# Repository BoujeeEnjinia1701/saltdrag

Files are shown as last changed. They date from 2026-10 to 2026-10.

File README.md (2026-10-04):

# SaltDrag

     

**Area:** Food and water security · **TRL:** 3 of 9 (analytical proof of concept, constructable design) · **Value-engineering target:** USD 4,000; estimated cost USD 2,803 · **Difficulty:** 3 of 5

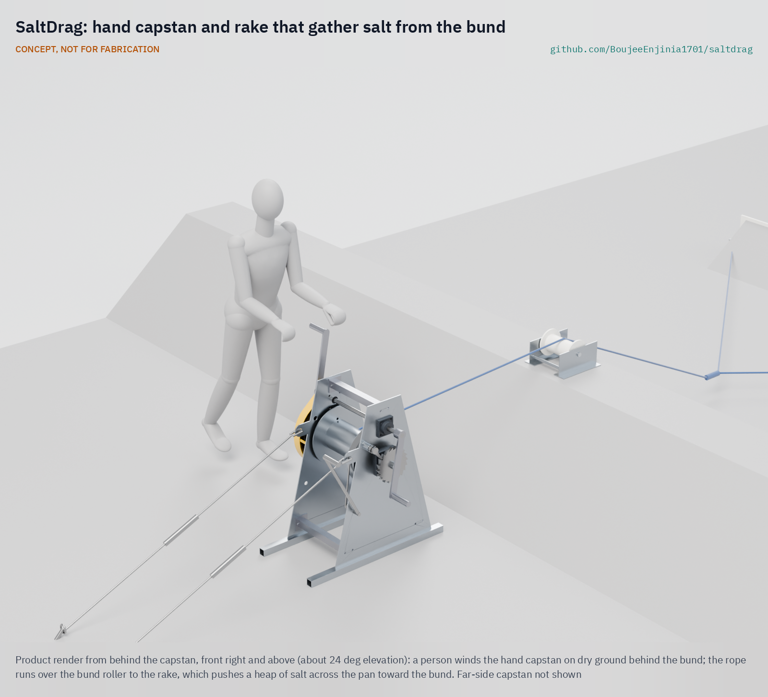
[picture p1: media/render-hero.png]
SaltDrag: hand capstan and rake that gather salt from the bund


[Exploded render](media/render-exploded.png) · [Detail render](media/render-detail.png) · [Interactive 3D model](media/viewer.html) · [Concept blueprint (PDF)](media/concept-blueprint.pdf)

Drags a rake across the salt pan with hand capstans on the bunds so workers stay out of the brine.

CONCEPT, NOT FOR FABRICATION: a TRL 3 design documented for building and testing, not a released or certified product.

## Concept rationale

Agariya families make salt by hand, and their own words describe the cost: from extreme winter to blazing sun they bear it all, and end up with grave injuries from constantly handling salt ([Mongabay India, 2021](https://india.mongabay.com/2021/10/when-salt-is-an-essential-commodity-and-salt-makers-are-not/)). SaltDrag moves the hardest part of the harvest out of the pan. A wide rake is laid across the pan and drawn over the crystal bed by ropes from two hand capstans set on the bunds. Workers wind the capstans from dry ground and the rake gathers the salt toward the bund, instead of people standing in the brine to scrape it.

It is hand powered on purpose. Agariyas received registration cards in 2023 on condition that they keep bunds to two feet and avoid machine use ([ICSF](https://icsf.net/newss/gujarat-in-kutch-booming-salt-business-puts-traditional-salt-agariyas-up-against-ginger-prawn-fishers/)), so a motorised harvester is not an option for them. A capstan and rake set that a local fabricator can build, within a prototype ceiling of $4,000 USD, and that a group of families can share, fits both the rules and the budget of a community that earns a small fraction of the retail price of its salt.

## Burning platform

About 60,000 Agariyas in the Little Rann of Kutch produce 30 per cent of India's inland salt, migrating to the pans for eight months a year; preparing each pan takes 40 to 45 days of manual work, and they earn about Rs 0.30 per kilogram for salt that retails at about Rs 20 ([Mongabay India, 2021](https://india.mongabay.com/2021/10/when-salt-is-an-essential-commodity-and-salt-makers-are-not/)). Salt pan workers there face severe health issues from working in harsh conditions for six to seven months at a stretch ([Wikipedia, citing The Diplomat](https://en.wikipedia.org/wiki/Little_Rann_of_Kutch)).

The collection season falls in the extreme heat of March and April ([Press Institute of India](https://pressinstitute.in/grassroots/traditional-salt-workers-contribute-to-wild-ass-conservation-and-regain-access-to-little-rann-of-kutch/)). Protective gear such as gumboots and caps has reached women workers through NGOs rather than employers ([Scroll.in](https://scroll.in/article/1007602/gujarats-plan-to-build-asias-biggest-freshwater-lake-is-a-threat-to-agariya-salt-workers)). The one big change in recent years, solar brine pumps, shows that the right hardware spreads fast: about 80 per cent of 7,000 Agariya families now have at least one solar pump ([Down To Earth](https://www.downtoearth.org.in/news/renewable-energy/great-change-in-little-rann-how-salt-workers-on-the-brink-in-gujarat-brought-about-a-solar-revolution-80652)). Harvesting has had no equivalent.

## Where it could be used

### By industry

| Industry | Use |
| --- | --- |
| Small-scale solar salt production | Gathering crystallised salt from inland and coastal pans without standing in brine |
| Cooperatives and producer groups | Shared harvest kit for a cluster of family pans |
| NGOs and livelihood programmes | Occupational health intervention alongside solar pumps and protective gear |
| Artisanal salt and specialty salt makers | Gentle, even gathering of large crystals from shallow pans |
| Evaporation pond operators | Low-cost manual scraping of small ponds and settling beds |

### By country or region

| Country or region | Why it matters there |
| --- | --- |
| India, Little Rann of Kutch | About 60,000 Agariyas produce 30 per cent of India's inland salt there by hand ([Mongabay India, 2021](https://india.mongabay.com/2021/10/when-salt-is-an-essential-commodity-and-salt-makers-are-not/)). |
| India, villages around the Rann | Agariyas migrate each season from 102 villages 7 to 45 km away, and 17.5 lakh people in the area depend on salt ([Scroll.in](https://scroll.in/article/1007602/gujarats-plan-to-build-asias-biggest-freshwater-lake-is-a-threat-to-agariya-salt-workers)). |
| India, Kutch coastal creeks | Salt works around Hadakiya Creek grew from 2,962 ha in 1995 to 15,950 ha in 2015, while Agariya registration requires two-foot bunds and no machine use ([ICSF](https://icsf.net/newss/gujarat-in-kutch-booming-salt-business-puts-traditional-salt-agariyas-up-against-ginger-prawn-fishers/)). |
| India, Gujarat | Gujarat produces 76 per cent of India's salt ([Press Institute of India](https://pressinstitute.in/grassroots/traditional-salt-workers-contribute-to-wild-ass-conservation-and-regain-access-to-little-rann-of-kutch/)). |

## What sparked the idea

An Agariya salt maker in the Little Rann of Kutch described the work this way: except pumping brine from the wells, everything is done manually, and "from extreme winter to blazing sun, we bear it all. And end up with grave injuries by constantly handling salt" ([Mongabay India, 2021](https://india.mongabay.com/2021/10/when-salt-is-an-essential-commodity-and-salt-makers-are-not/)). Solar pumps have changed the brine side of that sentence. SaltDrag is aimed at the other side: the handling.

## Problem

Small-scale salt makers such as the Agariyas of the Little Rann of Kutch gather crystallised salt by hand, working inside the pans for months in extreme heat and cold. There is no low-cost, non-motorised tool that lets them gather salt from the dry bund instead.

Full problem statement: [docs/01-problem.md](docs/01-problem.md)

## Concept

A 3 m rake is drawn across the salt pan by a rope from a hand capstan standing on dry ground behind the bund; the rope runs over a roller on the bund crest, and a second capstan on the far bund holds the rake straight and winds it back. Two people at 89 N each on 330 mm cranks pull a full heap of about 230 kg across a 30 m pan in under ten minutes (estimates, SDG-CAL-001). Every load-bearing part keeps at least a 2.1 margin at twice the rated 3 kN pull. The gathering rate against the traditional dantala is not yet known: it needs a baseline measured on a partner's pan.

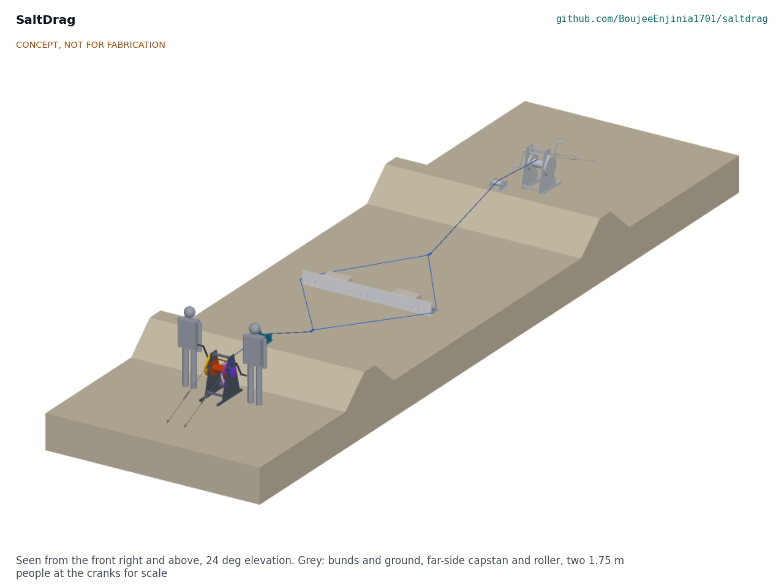
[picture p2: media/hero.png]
Working layout


Full design precis: [docs/02-concept.md](docs/02-concept.md) · Requirements: [docs/03-requirements.md](docs/03-requirements.md) · Calculations: [docs/04-calcs/01-sizing.md](docs/04-calcs/01-sizing.md) · Prototype build plan: [docs/05-build-plan.md](docs/05-build-plan.md) · Design decisions: [docs/06-design-decisions.md](docs/06-design-decisions.md) · General arrangement: [cad/drawings/SDG-DWG-001.pdf](cad/drawings/SDG-DWG-001.pdf) · 3D viewer: [media/viewer.html](media/viewer.html)

## Key components

- Hand capstans (two): geared drum winches, 6 to 1, with ratchet and pawl, band brake and gear guard
- Screw-in ground anchors and chains
- Bund roller saddles (two)
- Rake: 3.0 m FRP beam, 300 mm UHMW-PE blade, three skids, stainless end caps
- Pull ropes (12 mm polyester, 45 m each), bridles and swivels
- Rope dampers and ballast bags
- Maintenance kit

## Building the prototype

The build plan ([docs/05-build-plan.md](docs/05-build-plan.md)) takes a town fabrication shop through all 20 kinds of component in build order, with a making sketch for each made part, close-ups of the joints and a picture for every one of the 18 assembly steps. The capstans are cut, drilled and welded from steel plate and box section and then galvanised; the gears, bearings, anchors and ropes are bought; the rake is drilled FRP and plastic with stainless fittings. The plan is a plan, not yet built: it ends with first checks and the safety stops before any rope is loaded. The parts cost about USD 2,803 against a value-engineering target of USD 4,000.

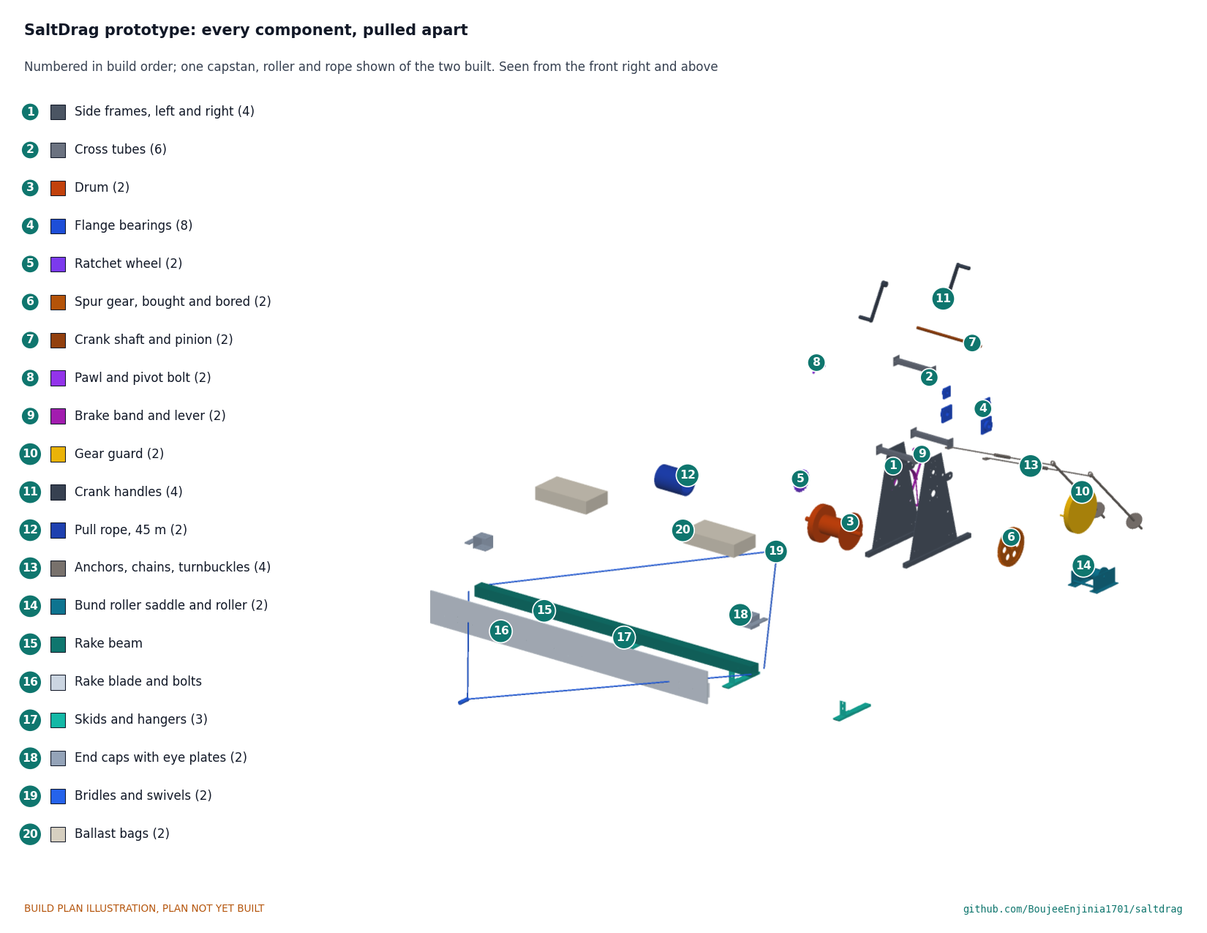
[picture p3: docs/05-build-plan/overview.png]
Every component, pulled apart and numbered in build order


## Safety

> Ropes under load can snap back. The design uses certified low-stretch polyester rope (working-load factor 7.7), a damper bag on every loaded rope and a 2 m exclusion zone along the rope line.
>
> Capstans have a pawl that is always engaged while winding, so a released crank cannot spin back; rope is paid out only on the band brake, with the crank handles removed. The gears run inside a guard.
>
> Ground anchors are proof-loaded on site before first use; the build plan lists safety stops before any rope load.
>
> Heat is a serious hazard in the harvest season; plan work for cooler hours and provide shade and water.
>
> Published as an open engineering reference, never as certified lifting or rope equipment.
>
> This design is published as an open engineering reference. It is not certified equipment.

## Repository layout

| Folder | Contents |
| --- | --- |
| `docs/` | Problem, concept, requirements, calculations, build plan and design decisions |
| `cad/src/` | build123d Python source, the source of truth for all geometry |
| `cad/step/`, `cad/stl/` | Exported models for FreeCAD, other CAD tools and printing |
| `cad/drawings/` | 2D sketches and dimensioned drawings |
| `bom/` | Bill of materials |
| `electronics/` | KiCad schematics and PCB layouts |
| `firmware/` | Microcontroller code |
| `media/` | Renders, perspectives and photos |
| `build-log/` | Dated prototyping notes |

## Documentation

Controlled documents follow the portfolio [documentation standard](.kit/STANDARDS.md). Each carries a document ID (SDG-PRC-001 for the precis), a version and a revision history. Branded PDFs are built with `python .kit/render.py` and attached to GitHub Releases when a document is tagged, for example `SDG-PRC-001/v1.0`.

## Credits

Designed by Amish Chadha at Design Molecule Labs. See [CONTRIBUTORS.md](CONTRIBUTORS.md) for roles. To cite this design, use [CITATION.cff](CITATION.cff) (GitHub shows it as "Cite this repository").

AI assistance (Claude) was used to accelerate prototype documentation and first-pass research. Design direction and all decisions are Amish Chadha's, recorded in this repository's decision records (`docs/decisions/`).

## Licenses

- **Hardware** (CAD, drawings, BOM, electronics): [CERN-OHL-S v2](LICENSE)
- **Software** (firmware, scripts, notebooks): [MIT](LICENSE-SOFTWARE)

A project of the [Design Molecule](https://designmolecule.com) lab.

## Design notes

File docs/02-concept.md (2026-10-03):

---
doc_id: SDG-PRC-001
title: SaltDrag design precis
project: SaltDrag
doc_type: Precis
version: "0.3"
status: Draft
date: '2026-10-03'
author: Amish Chadha
license: CERN-OHL-S-2.0
revisions:
- version: "0.1"
  date: '2026-09-30'
  author: Amish Chadha
  change: Initial scaffold
- version: "0.2"
  date: '2026-10-03'
  author: Amish Chadha
  change: TRL 2 precis; how it works, components, key design choices, first-order numbers, safety and concept media (SDG-DDR-001)
- version: "0.3"
  date: '2026-10-03'
  author: Amish Chadha
  change: TRL 3; numbers from SDG-CAL-001 and the constructable design (SDG-DDR-002); bund roller and ballast added, windrow board removed
---

# SaltDrag design precis

Drags a rake across the salt pan with hand capstans on the bunds so workers stay out of the brine.

Figure 1. SaltDrag working layout

*Figure 1. The working layout on a pan shortened to 7 m for the picture: the near capstan and bund roller in colour, the far-side set in grey, two 1.75 m people at the cranks for scale (concept media, SDG-DWG-010).*

## How it works

Two people winding a hand capstan on dry ground behind one bund draw a 3 m rake across the pan by a rope that runs over a roller on the bund crest. The rake's plastic blade rides 10 mm above the floor on three skids and pushes the loose salt crystals ahead of it into a heap of about 230 kg. At the near bund the steepening rope starts to lift the rake about 3.3 m from the bund toe, so the heap is left there as a windrow. A second capstan on the far bund holds a light back tension while the rake is pulled in, then winds it back empty. Both capstans then move 3 m along their bunds, and the return pull brings the rake onto the next strip. Nobody stands in the brine or walks on the pan at any stage.

Each capstan is a geared hand winch: two cranks drive a 14-tooth pinion, which turns an 84-tooth gear on the drum shaft (6 to 1). A pawl on a ratchet wheel stops the drum running back whenever the cranks are let go, and a band brake lets the far capstan pay out rope under control. Two chains from ears on the side frames, at rope height, hold the capstan to two screw-in ground anchors behind it.

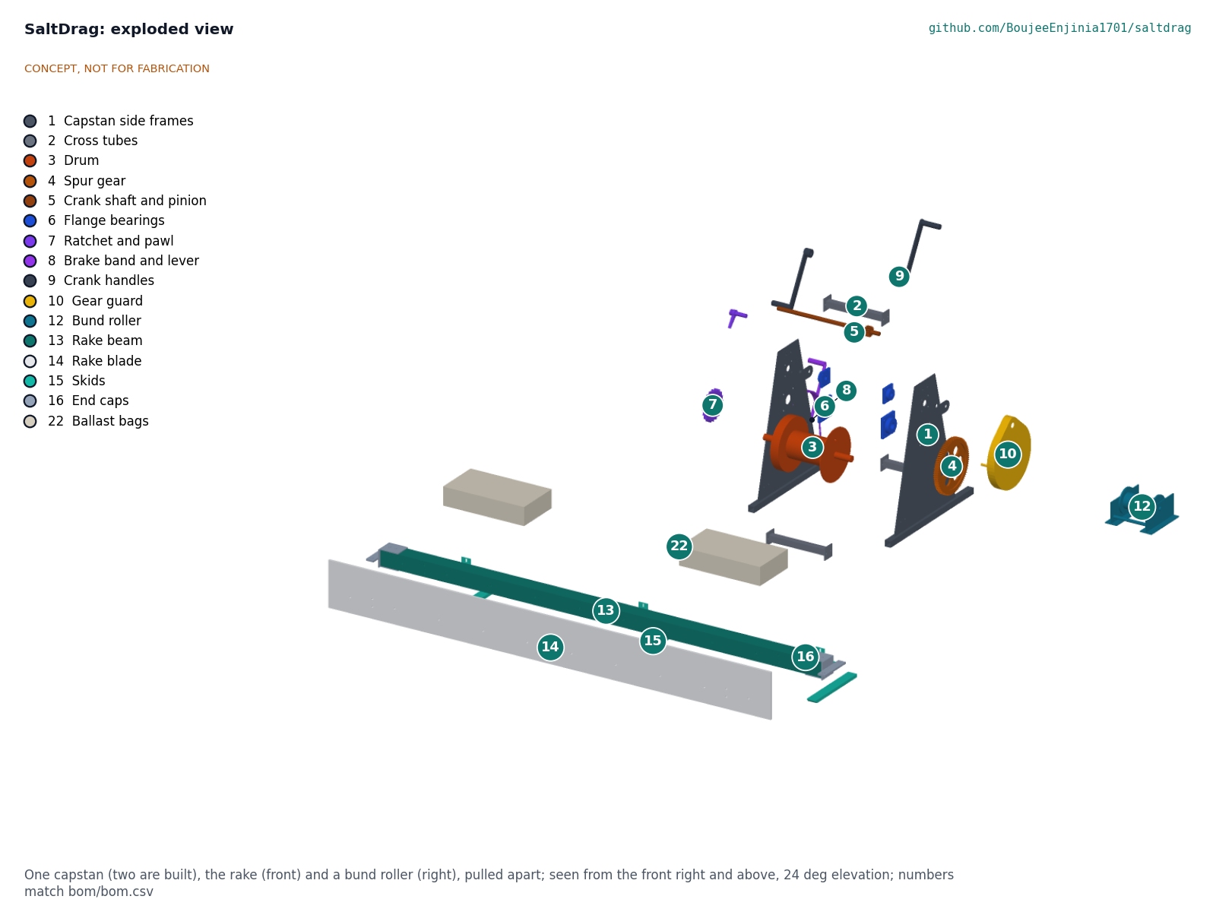
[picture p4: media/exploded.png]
Figure 2. Exploded view


*Figure 2. One capstan, the rake and a bund roller pulled apart; numbers match bom/bom.csv.*

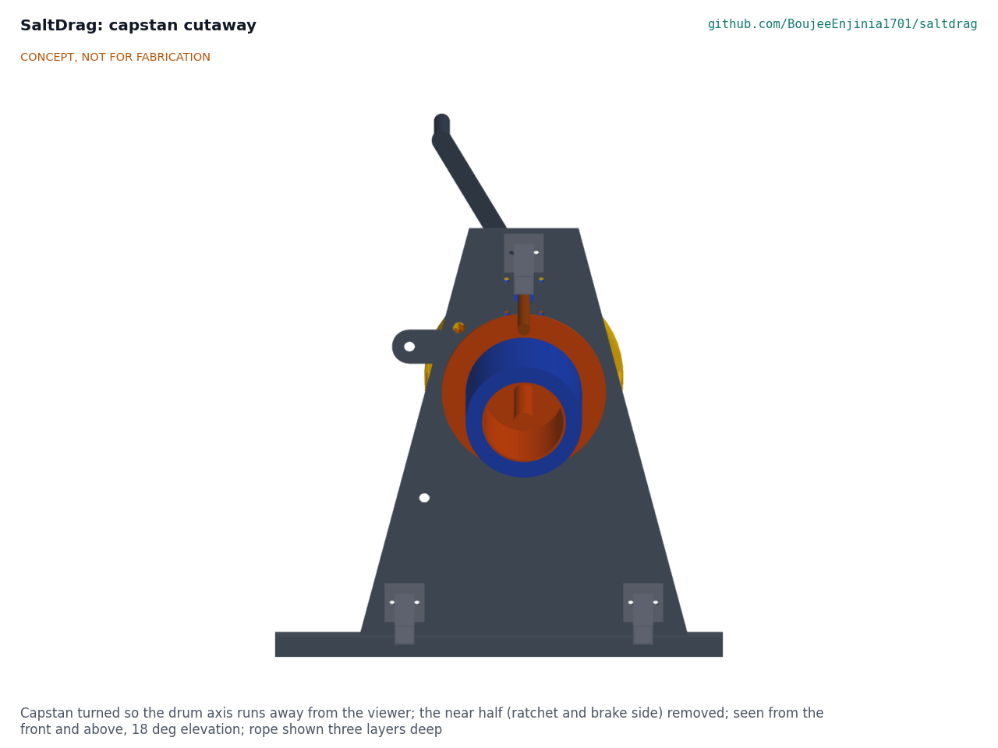
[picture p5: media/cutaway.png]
Figure 3. Capstan cutaway


*Figure 3. Capstan with its ratchet and brake side removed, showing the drum, flanges and three layers of rope.*

## Components

*Table 1. Main components (two capstans, two rollers and two ropes in a set).*

| BOM | Component | Role |
| --- | --- | --- |
| 1, 2 | Side frames and cross tubes | Two 6 mm galvanised cheeks on box-section runners, bolted together by three cross tubes; the runners let the capstan be slid along the bund |
| 3 | Drum | 168 mm barrel between 330 mm flanges on a 40 mm shaft; holds 58 m of 12 mm rope; the left flange carries the brake rim |
| 4, 5, 9 | Gear, crank shaft and pinion, crank handles | Module 4 spur gears, 6 to 1; two removable 330 mm cranks set 180 degrees apart |
| 6 | Flange bearings | Four-bolt bearings with stainless inserts in thermoplastic housings |
| 7, 8 | Ratchet and pawl; brake band and lever | The pawl holds the load; the band brake controls paying out |
| 10 | Gear guard | Yellow sheet-steel cup over the gear mesh |
| 11 | Ground anchors, chains and turnbuckles | Two screw-in anchors per capstan, chained to the cheek ears |
| 12 | Bund roller saddle | UHMW-PE roller on a small galvanised saddle astride the crest, so the rope never cuts the bund |
| 13 to 16 | Rake beam, blade, skids, end caps | 3.0 m FRP box beam with a 300 mm UHMW-PE blade; skids set the blade height; stainless end caps carry the bridle eyes |
| 17, 18 | Bridles and pull ropes | Two-leg polyester bridles to a swivel; 45 m of 12 mm polyester double braid per side |
| 20, 22 | Rope dampers and ballast bags | A weighted bag on each loaded rope; two salt-filled bags keep the blade down near the bund |
| 21 | Maintenance kit | Rinse water, grease and spares |

## Key design choices

All were decided on 2026-10-03 under Amish's pre-approval of this batch (SDG-DDR-001 and SDG-DDR-002; register SDG-DEC-001).

- **Drum winch, not a warping capstan.** The drum stores the rope, so nobody has to tail a loaded rope by hand.
- **Capstan behind the bund, roller on the crest.** A 0.4 m crest is too narrow for a capstan and two people cranking, and the roller keeps the rope off the bund.
- **Hand power, single spur stage.** No engine or motor, in keeping with the Agariya registration conditions.
- **Plastic and FRP in the pan, galvanised steel on dry ground.** Nothing that rusts sits in the brine.
- **One-piece 3 m rake with ballast.** The rake width keeps the design drag at the rated 3 kN; salt-filled bags keep the blade down as the rope steepens near the bund.

## First-order numbers

*Table 2. Key figures (estimates from SDG-CAL-001).*

| Quantity | Value | Basis |
| --- | --- | --- |
| Full heap in front of the blade | 0.19 m³, about 231 kg | 300 mm blade, 35 degree repose, 1,200 kg/m³ loose salt |
| Design drag on the rake | 2.75 kN | Heap sliding 1.59 kN, layer loosening 0.90 kN (assumed 300 N/m), skids 0.26 kN |
| Rope pull at the drum | 3.0 kN | Drag, roller loss and 200 N back tension |
| Crank force, two people | 89 N each | 6 to 1, 330 mm cranks, 94 % gear and bearing efficiency, rope on its third layer |
| Pull with two people at 120 N | 4.0 kN (3.7 kN on a full drum) | R3 asks for 3 kN |
| Rope speed and work rate | 3.1 m/min at 30 crank turns a minute; 84 W each | Light to moderate work, early hours in the hot season |
| One strip | 23 min: pull 9.5, return 5.7, move 8 | 30 m pan |
| Gathering rate | About 600 kg/h, 150 kg per worker-hour (crew of four) | Baseline for R5 still to be measured |
| Heaviest single part | 23.8 kg (ballast bag, filled on site); drum 21.3 kg | Model masses |
| Parts cost of the set | USD 2,803 | Value-engineering target USD 4,000 (USD 1,197 under) |

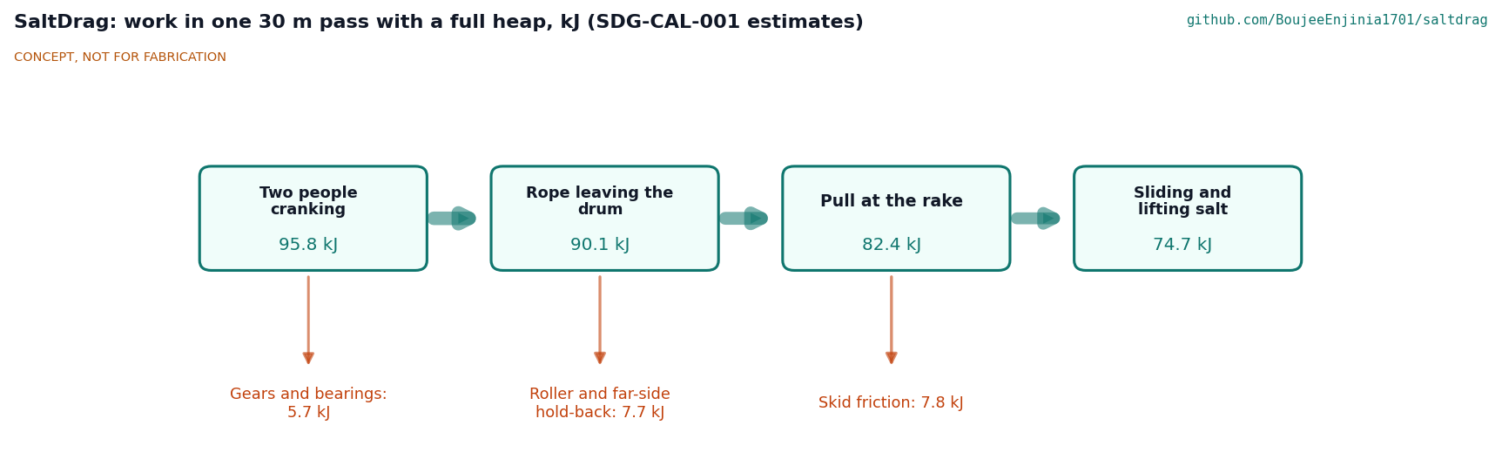
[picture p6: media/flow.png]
Figure 4. Work in one pass


*Figure 4. Where the cranking work goes in one 30 m pass with a full heap (estimates).*

## Patent design-arounds

From the preliminary patent, trademark and prior-art screen (not legal advice):

- No motorised or track-mounted auger harvester.
- Build on expired prior art such as the CA1243940A salt harvester; review CN102476810A (salt-pan rake) claims before release.

## Shared blocks

- Hand capstan common block, shared with SiltHaul: this capstan is the first candidate for the common block (SDG-DDR-001). SiltHaul is not changed by this work.
- CalRig proof-load for rope, capstan and anchor load tests.

## Safety

> **Safety:** A loaded rope stores energy and can whip back if it breaks, slips off the drum or loses its anchor. The rope is low-stretch polyester with a working-load factor of 7.7 at the rated pull, each loaded rope carries a weighted damper bag at mid-span, and nobody stands in line with a loaded rope or on the bund within 2 m of it.

> **Safety:** Cranks and gears can strike or trap hands. The pawl is always engaged while winding, so a released crank cannot spin back; the gears run inside a yellow guard; the crank handles are taken off before any rope is paid out under load, and paying out is done only on the brake.

> **Safety:** A ground anchor that pulls out lets the capstan lurch toward the pan. Each anchor is proof-loaded on site to 1.5 times its share of the rated pull before first use, and the chains are fixed at rope height so the capstan cannot tip.

> **Safety:** Heat is a serious hazard in the harvest season; plan work for cooler hours and provide shade and water. Parts of up to 24 kg are lifted and carried; lift in pairs.

This design is published as an open engineering reference, never as certified lifting or rope equipment. It is not certified equipment.

## Open questions

No design decisions are open (register SDG-DEC-001). Facts that only a site survey or real parts can settle, such as the drag per metre on a real crystal bed, the bund crest width and the soil behind the bunds, are listed in the register to be confirmed.

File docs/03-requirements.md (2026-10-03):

---
doc_id: SDG-REQ-001
title: SaltDrag requirements
project: SaltDrag
doc_type: Requirements
version: "0.3"
status: Draft
date: '2026-10-03'
author: Amish Chadha
license: CERN-OHL-S-2.0
revisions:
- version: "0.1"
  date: '2026-09-30'
  author: Amish Chadha
  change: Initial scaffold
- version: "0.2"
  date: '2026-10-03'
  author: Amish Chadha
  change: TRL 2; every target made measurable; R10 to R12 added for rope, holding and rope capacity (SDG-DDR-001)
- version: "0.3"
  date: '2026-10-03'
  author: Amish Chadha
  change: TRL 3 status from SDG-CAL-001 against the constructable design (SDG-DDR-002); R5 not verified
---

# SaltDrag requirements

Eleven of the twelve requirements are met on paper by the constructable design; R5, the gathering rate against the dantala, cannot be shown until the dantala baseline is measured on a partner's pan. Status is from the sizing note SDG-CAL-001 (estimates). Physical verification is TRL 4 and TRL 5 work.

*Table 1. Requirements and their status at TRL 3.*

| ID | Requirement | Target | Verification (TRL 4 or later) | TRL 3 status |
| --- | --- | --- | --- | --- |
| R1 | Work from the bund | A full harvest pass, including set-up and moving to the next strip, with no worker entering the pan | Observed field trial on a partner pan | Met by design: crews stand on dry ground behind the bunds; the return pull re-aligns the rake |
| R2 | Manageable crank effort | 120 N or less at each of two handles for the design rake load | Spring scale on the handle during trials | Met: 89 N estimated [B3] |
| R3 | Pull capacity | At least 3 kN rope pull from two people at 120 N; every load-bearing part at least 2 to 1 on yield or rated strength at 6 kN | Proof-load test with CalRig | Met: 4.0 kN at the end of a 30 m pass, 3.7 kN on a full drum [B4], [B5]; lowest margin 2.1 [C2b] |
| R4 | Protect the pan floor | Blade edge 5 to 25 mm above the floor; no steel in the pan; skid pressure 15 kPa or less; no visible cutting or cracking after 20 passes | Inspection of a test pan after trial passes | Met by design: 10 mm edge, 10.7 kPa [D1], [D2]; floor check at TRL 5 |
| R5 | Gathering rate | At least as many kilograms per worker-hour as the dantala method on the same pan | Side-by-side timed harvest trial | **Not verified**: no baseline yet; estimate 150 kg per worker-hour [D9] |
| R6 | Portable | Heaviest single part 25 kg or less; every part of the set carried by up to four people | Weigh parts; timed move between pans | Met: heaviest 23.8 kg (a ballast bag filled on site), drum 21.3 kg [E1] |
| R7 | Corrosion resistance | No loss of function after one season in brine and salt with a daily freshwater rinse | Season-long field trial with inspection log | Met by design: galvanised steel above the bund; FRP, UHMW-PE and 316 stainless in the pan |
| R8 | Quick set-up | Capstans anchored and rake rigged in 20 minutes or less (two crews at once) | Timed trials | Met: 19 min estimated [D10], small margin |
| R9 | Value engineering | Parts cost of the full set against the value-engineering target of USD 4,000 | Costed bill of materials | USD 2,803, USD 1,197 under the target [E2], [E3] |
| R10 | Rope safety | Rope minimum breaking strength, after splices, at least 5 times the rated 3 kN pull | Rope certificate; proof load | Met: 7.7 [C8] |
| R11 | Holding | Pawl holds 6 kN; brake holds 3 kN with a hand force of 150 N or less; each ground anchor holds at least 1.5 times its share of the rated pull (proof-loaded on site before use) | Proof-load test with CalRig; anchor pull test on site | Met on paper: pawl boss margin 4.7 [C5b], brake 92 N [C7], anchor 2.4 times its 6 kN chain force [C10b] (soil to confirm) |
| R12 | Pan coverage | Each drum stores at least 45 m of rope, for pans up to 30 m between bund crests | Wind on and measure | Met: 58 m in four layers, 38 mm flange freeboard [B8], [B9] |

## Assumptions

- The drag of a rake on a crystallised bed is about 0.9 kN per metre of blade with a full heap (SDG-CAL-001, Section A); this is the main uncertainty and is measured with the partner before the first build is loaded.
- Hand capstans are not treated as machines under Agariya registration conditions; written clarification is sought through the partner before any trial.
- Several families can share one set across a harvest season.
- Salt gathered into the windrow, about 3.3 m from the bund toe, is loaded with existing methods (out of scope).
- The pans have dry, firm ground behind the bunds on the two sides where the capstans stand.

> **Safety:** R3, R10 and R11 are safety requirements. A load-bearing part that misses its margin, a rope without a certificate, or an anchor that fails its proof load on site stops the work until it is replaced (SDG-BLD-001, Safety stops).

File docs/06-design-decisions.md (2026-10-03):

---
doc_id: SDG-DEC-001
title: SaltDrag design decisions register
project: SaltDrag
doc_type: Design decisions register
version: "0.1"
status: Draft
date: '2026-10-03'
author: Amish Chadha
license: CERN-OHL-S-2.0
revisions:
- version: "0.1"
  date: '2026-10-03'
  author: Amish Chadha
  change: Register opened at TRL 3; every decision made under Amish's 2026-10-03 pre-approval
---

# SaltDrag design decisions register

Every design decision still to be made, and every decision made, in one place. Each decision is argued in full in its decision record under `docs/decisions/`; this register is the index Amish works from. The build plan (`docs/05-build-plan.md`) describes the design as it stands and does not list open decisions.

## Open decisions

None. All decisions were made under Amish's 2026-10-03 pre-approval.

## To confirm when parts are bought

| # | What to confirm | Why it matters | Source |
| --- | --- | --- | --- |
| 1 | The rope certificate shows a minimum breaking strength of at least 25 kN for the 12 mm polyester double braid, with eye splices | The 7.7 working-load factor (R10) rests on it | SDG-CAL-001 [C8] |
| 2 | The bought gear and pinion are module 4, 20 degree pressure angle, C45 or better, and the gear blank is webbed (about 10 kg) | Tooth strength, mesh at 196 mm centres and the part mass | SDG-CAL-001 [C3]; SDG-DDR-002 |
| 3 | The flange bearings fit 40 mm and 25 mm shafts on bolt squares of 102 mm and 70 mm, with stainless inserts | The cheek holes are drilled to these squares | SDG-DWG-101 |
| 4 | The chain, turnbuckles and shackles carry working load limits of at least 7.8 kN, 6 kN and 10 kN | The 2.4 margin on the chain line | SDG-CAL-001 [C9b] |
| 5 | The FRP tube's maker gives a flexural strength of 200 MPa or more | The beam margin of 7.1 | SDG-CAL-001 [C13b] |
| 6 | Each helical anchor holds at least 2.25 kN (1.5 times its share of the rated pull) in the proof pull on site, at the trial pan | The soil strength is assumed at 50 kPa; the anchors are a safety stop | SDG-CAL-001 [C10]; SDG-DDR-001, D11 |
| 7 | The drag of the rake on the partner's crystal bed, measured with a spring scale or CalRig on a short trial rake | The design drag and rope pull rest on an assumed 300 N per metre; if higher, raise the skids or shorten the rake | SDG-CAL-001, Section A |
| 8 | The bund crest is at least 0.35 m wide and the ground behind the bund is firm and dry on both capstan sides of the trial pan | The roller saddle footprint and capstan position assume it | SDG-PRB-001; SDG-DDR-001, D2 |

## Value engineering

Value-engineering target: USD 4,000 (a hypothetical control target, not a limit). Estimated cost of the constructable design: USD 2,803 (USD 1,197 under the target). Main cost drivers and savings worth trying:

- The largest lines are fabrication labour and galvanising (USD 450), the four side frames (USD 220), the two drums (USD 220), the two bought gears (USD 190), the rake blade (USD 190) and the two pull ropes (USD 190).
- The four flange bearings with stainless inserts (USD 264 for eight) cost about twice plain cast-iron bearings; they stay because the capstans stand in salt dust and are rinsed daily.
- Savings worth trying: a single gear pair cut in a local workshop in place of bought gears; a laser-cut cheek nested with the ratchet wheel and pawl to cut plate waste; sharing one set between several families' pans, which spreads the cost per family.

## Decisions made

| Date | Decision | Decided by | Record |
| --- | --- | --- | --- |
| 2026-10-03 | Geared drum winch (still called a hand capstan) rather than a warping capstan | Amish, pre-approval: "I pre-approve the batch runs along with any recommendations you come up with." | SDG-DDR-001, D1 |
| 2026-10-03 | Capstan on dry ground 1.5 m behind the bund crest, with a bund roller saddle on the crest | Amish, same pre-approval | SDG-DDR-001, D2 |
| 2026-10-03 | Single spur stage 6 to 1, module 4; two 330 mm cranks 180 degrees apart | Amish, same pre-approval | SDG-DDR-001, D3 |
| 2026-10-03 | 12 mm polyester double braid rope, 45 m per side | Amish, same pre-approval | SDG-DDR-001, D4 |
| 2026-10-03 | One-piece 3.0 m FRP rake with a 300 mm UHMW-PE blade; three adjustable skids, blade 10 mm above the floor | Amish, same pre-approval | SDG-DDR-001, D5 and D6 |
| 2026-10-03 | Two helical ground anchors per capstan, chained at rope height | Amish, same pre-approval | SDG-DDR-001, D7 |
| 2026-10-03 | Galvanised steel on dry ground; FRP, UHMW-PE and 316 stainless in the pan; stainless-insert bearings; daily rinse | Amish, same pre-approval | SDG-DDR-001, D8 |
| 2026-10-03 | Safety: pawl always engaged while winding; pay out only on the brake with the cranks removed; rope dampers and a 2 m exclusion zone; anchors proof-loaded on site to 1.5 times their share | Amish, same pre-approval (conservative options) | SDG-DDR-001, D9 to D11 |
| 2026-10-03 | Design pan 30 m between crests; crew of four | Amish, same pre-approval | SDG-DDR-001, D12 and D13 |
| 2026-10-03 | First co-design partner to approach: SEWA; first trial region: Little Rann of Kutch (candidates, not agreed) | Amish, same pre-approval | SDG-DDR-001, D14 and D15 |
| 2026-10-03 | Seek written clarification from the forest department, through the partner, that a hand capstan is not a machine | Amish, same pre-approval | SDG-DDR-001, D16 |
| 2026-10-03 | SaltDrag capstan offered as the first candidate for the hand capstan block shared with SiltHaul | Amish, same pre-approval | SDG-DDR-001, D17 |
| 2026-10-03 | Design for construction: bolted side frames and cross tubes, welded drum with brake rim, flange bearings, bought gears, pawl on a welded boss, differential band brake, removable cranks, gear guard, anchor ears and chains, one-piece rake with crush-sleeved bolts, slotted skid hangers, end caps with eye plates | Amish, same pre-approval | SDG-DDR-002, changes 1 to 14 |
| 2026-10-03 | Ballast bags on the rake; windrow board removed (the windrow forms about 3.3 m from the bund toe); rope dampers added | Amish, same pre-approval | SDG-DDR-002, changes 15 to 17 |
| 2026-10-03 | Estimated cost reported against the unchanged value-engineering target of USD 4,000 | Amish: "I also accept any cost overruns or variations from the assumed scope cost." | This register |

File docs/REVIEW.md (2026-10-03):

# Review note: SaltDrag

## Session 2026-09-30: scaffolded

### What was done

- Repository created from kit 1.6.0 at TRL 1, target TRL 2.
- `docs/01-problem.md` (SDG-PRB-001 v0.1): problem with cited evidence, users, environment, constraints, prior work, open questions.
- `docs/02-concept.md` (SDG-PRC-001 v0.1): how it works, components, patent design-arounds, shared blocks, safety.
- `docs/03-requirements.md` (SDG-REQ-001 v0.1): 9 proposed requirements.
- `README.md` with concept rationale, burning platform, where it could be used, and what sparked the idea.

### Next

- Run `/populate` to bring the repo to a strong TRL 2 with concept media.

## Session 2026-10-03: TRL 2 (/populate, kit 1.7.0)

Kit 1.7.0 installed (`.kit/`, `.claude/commands/`, root `CLAUDE.md` from `.kit/CLAUDE.md`). Run under Amish's pre-approval of 2026-10-03: "start with the first 14 repos from the list of 29 projects. I pre-approve the batch runs along with any recommendations you come up with. I also accept any cost overruns or variations from the assumed scope cost." Every recommendation is therefore recorded as decided, not proposed.

### What was done

- `docs/01-problem.md` (SDG-PRB-001 v0.2): site assumptions stated (30 m design pan, 0.4 m crest, dry ground behind the bunds), co-design checklist, safety section, open questions answered where the work settles them.
- `docs/03-requirements.md` (SDG-REQ-001 v0.2): every target measurable; R10 (rope safety), R11 (holding) and R12 (rope capacity) added.
- `docs/02-concept.md` (SDG-PRC-001 v0.2): how it works, components, key design choices, first-order numbers, safety, concept media.
- `docs/decisions/0001-trl2-review-decisions.md` (SDG-DDR-001): TRL 2 review decisions D1 to D17.
- Concept media from `cad/src/concept_media.py`: `media/hero.png`, `media/concept-blueprint.png`, `.pdf` and `.svg` (SDG-DWG-010), `media/model.glb` (about 4 MB) and `media/viewer.html`, `media/exploded.png`, `media/cutaway.png`, `media/flow.png` (work per pass, estimates).
- `bom/bom.csv`: every line priced.

### Results

- A geared drum winch (6 to 1, two 330 mm cranks) on dry ground behind the bund, a roller on the crest, and a 3 m FRP and UHMW-PE rake set to 10 mm above the floor.
- The rake width follows from the drag estimate: a full 230 kg heap gives a design rope pull of 3.0 kN, the rated pull.

### Requirements not met

- R5 (gathering rate at least the dantala's) cannot be shown: there is no baseline yet.

### Decisions made under the pre-approval

SDG-DDR-001, D1 to D17: drum winch, capstan behind the bund with a crest roller, single spur stage, polyester rope, one-piece FRP rake, adjustable skids, helical anchors chained at rope height, materials for brine, conservative safety rules (pawl always on, pay out on the brake with cranks removed, dampers and a 2 m exclusion zone, anchors proof-loaded on site), 30 m design pan, crew of four, SEWA as the first co-design partner to approach and the Little Rann as the first trial region (candidates, not agreed), written clarification on the machine-use condition, and the capstan as the first candidate for the block shared with SiltHaul.

### Safety concerns

Rope snap-back, cranks and gears, anchor pull-out and heat. See SDG-PRC-001, Safety.

## Session 2026-10-03: TRL 3 (/advance-trl3 and /build-plan)

### What was done

- `docs/04-calcs/01-sizing.md` (SDG-CAL-001 v0.2) with `docs/04-calcs/sizing.py` and `docs/04-calcs/results.csv`: drag, capstan, strength at 6 kN, floor, lift-off near the bund, rate, set-up, mass and cost, with a results table against every requirement.
- `cad/src/model.py`: parametric build123d model of the capstan, rake, roller and layout, with 63 constructability checks (`--check`: 63 of 63 pass). STEP and STL in `cad/step/` and `cad/stl/` (capstan, rake, roller; assembly STEP of the layout).
- `cad/src/sheets.py`: general arrangement SDG-DWG-001 Rev P2 (Rev P1 superseded the same day by the design for construction).
- `cad/src/build_plan_media.py`: overview, 13 making sketches (SDG-DWG-101 to 113), 11 joint close-ups and 18 step pictures.
- `docs/05-build-plan.md` (SDG-BLD-001 v0.1), `docs/06-design-decisions.md` (SDG-DEC-001 v0.1), `docs/decisions/0002-design-for-construction.md` (SDG-DDR-002).
- `cad/src/product_model.py` (`product_parts()`, `TITLE`, `RENDER_VIEWS` hero, exploded and detail) and render scenes exported to `/home/claude/renders/saltdrag` for the photoreal renders on Amish's Mac.
- `docs/02-concept.md` v0.3, `docs/03-requirements.md` v0.3, `README.md` (TRL 3, hero render, links, Building the prototype), `project.yaml` (trl 3, trl_target 3, design_state constructable, trl_evidence). `budget_usd` unchanged.

### Results (estimates, SDG-CAL-001)

- Crank force 89 N per handle at the design drag (R2: 120 N); two people at 120 N pull 4.0 kN (3.7 kN on a full drum) against 3 kN asked (R3).
- Lowest strength margin at 6 kN: crank shaft 2.1 on yield; rope working-load factor 7.7; anchors 2.4 on their chain force (soil assumed).
- A 30 m pass takes 9.5 min; one strip 23 min; about 600 kg/h, 150 kg per worker-hour for a crew of four.
- Capstan 102 kg assembled; heaviest single part 23.8 kg (a ballast bag filled on site), drum 21.3 kg.
- Value-engineering target: USD 4,000. Estimated cost of the constructable design: USD 2,803 (USD 1,197 under the target).

### Requirements not met

- R5 is not verified: no dantala baseline. The estimate of 150 kg per worker-hour may be below the dantala rate; if it is, the cycle (8 min moving per 3 m strip) is the first place to look.
- R8 is met with a small margin (19 min against 20).

### Decisions made under the pre-approval

- SDG-DDR-002, changes 1 to 17 (below), and the value-engineering wording of the cost.
- Open decisions in SDG-DEC-001: none. Eight facts to confirm when parts are bought or at the trial pan are listed there (rope certificate, gears, bearings, rigging ratings, FRP strength, anchor holding, measured drag, bund and ground survey).

### Design changes made for construction (SDG-DDR-002)

1. Capstan frame of two bolted side frames (cheek on runner) and three cross tubes.
2. Capstan on dry ground behind the bund; bund roller saddle on the crest (new BOM 12).
3. Welded drum with brake rim; rope over the top.
4. Flange bearings on the cheeks (new line 6b for the 25 mm size).
5. Bought webbed gear and pinion, keyed.
6. Pawl on a 40 mm welded boss (a plain pin would bend at 6 kN).
7. Differential band brake through the left cheek.
8. Removable crank handles with cross pins.
9. Gear guard.
10. Anchor ears at rope height, shackles, chains and turnbuckles (new line 11b).
11. One-piece 3 m FRP beam.
12. Blade bolts with crush sleeves.
13. Skids on slotted stainless hangers.
14. End caps with eye plates for the bridles.
15. Ballast bags (new line 22): without them the rope lifts the blade 5.9 m from the bund toe; with them, 3.3 m.
16. Windrow board removed: the windrow forms about 3.3 m from the toe.
17. Rope dampers (new line 20); fabrication labour and galvanising priced as line 23.

### Build plan findings

- The near-bund lift-off is the main finding the concept missed; it sets the windrow 3.3 m into the pan, so loading out still uses existing methods.
- Moving both capstans 3 m per strip (8 min) is a third of the cycle; a sliding anchor line along the bund is worth studying at TRL 4.
- The drum and gears must be bought or machined; everything else is town-workshop work.

### Appearance model and render scenes

- `cad/src/product_model.py` takes every part from `model.py`'s layout. Departures from `model.py`: the ground anchors are cut off at ground level (they are buried), the crank is drawn at 100 degrees (`crank_angle`) so the cranking figure's hands meet the upper handle, the rake is drawn 2.5 m from the bund toe with a heap of salt in front of it (context), and the far-side set is not shown. Decided under the pre-approval.
- Scenes exported with `.kit/export_views.py` to `/home/claude/renders/saltdrag` (hero, exploded, detail). `media/render-hero.png` is made on Amish's Mac; until then `render.py --check` warns that it is missing.

### Safety concerns

- Rope snap-back: certified rope, dampers, exclusion zone; safety stops S2, S3 and S5.
- Cranks and gears: guard, pawl always on, cranks off before paying out (S4).
- Anchor pull-out: on-site proof pull of every anchor (S6, S7); soil strength is an assumption.
- Heat in the harvest season: work in cooler hours with shade and water; each cranker works at about 84 W.
- The drag per metre is assumed; it is measured before the first loaded pass (SDG-DEC-001, item 7).

### Recommended next step

The design is ready for TRL 4 on paper. Recommendation: with the co-design partner, measure the drag of a short trial rake and time the dantala on the same pan, then build one capstan and proof-load it with CalRig before building the full set.

### Cross-repo note (not edited)

SiltHaul names the hand capstan as a shared block; SaltDrag's capstan (SDG-DWG-101 to 108) is offered as the first candidate.

## 2026-10-03: photoreal renders

Rendered with Blender Cycles on Amish's Mac from `cad/src/product_model.py`; captioned with `.kit/photo_caption.py`; `media/card.png` and `media/social-preview.png` made with `.kit/cards.py`. Views: hero, exploded, detail. image_qc passes and `render.py --check` has no FAIL.

2026-10-03: hero render reframed so the product fills the frame (saltdrag).

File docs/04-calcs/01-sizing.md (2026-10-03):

---
doc_id: SDG-CAL-001
title: SaltDrag sizing calculations
project: SaltDrag
doc_type: Calculation
version: "0.2"
status: Draft
date: '2026-10-03'
author: Amish Chadha
license: CERN-OHL-S-2.0
revisions:
- version: "0.1"
  date: '2026-10-03'
  author: Amish Chadha
  change: First sizing note at TRL 3 (drag, capstan, strength, floor, rate, mass and cost)
- version: "0.2"
  date: '2026-10-03'
  author: Amish Chadha
  change: Rerun on the constructable design (SDG-DDR-002); pawl boss, ballast and lift-off near the bund added
---

# SaltDrag sizing calculations

Two people at 89 N each on 330 mm cranks can pull a 3 m rake with a full 230 kg heap across a 30 m pan in under ten minutes, and every load-bearing part keeps at least a 2.1 margin on yield at twice the rated 3 kN pull. Eleven of twelve requirements are met on paper. R5, the gathering rate against the dantala, cannot be shown until the dantala baseline is measured; the estimate is 150 kg per worker-hour. The largest uncertainty is the drag of a rake on a real crystal bed, which is assumed here and must be measured before the first build is loaded.

## Scope and method

First-order hand calculations, scripted in `docs/04-calcs/sizing.py`, which reads its geometry and masses from the parametric model (`cad/src/model.py`) and the bill of materials, prints every result with a label in square brackets, and writes `docs/04-calcs/results.csv`. Strength checks use twice the rated rope pull (6 kN), as R3 asks. All results are estimates for TRL 3; none is a test result.

## Assumptions

*Table 1. Assumptions (every one is in the script's ASSUME list).*

| Assumption | Value | Basis |
| --- | --- | --- |
| Loose salt bulk density | 1,200 kg/m³ | Typical 1,100 to 1,300 for crystallised salt |
| Heap repose angle; heap sliding friction | 35 degrees; 0.70 | Granular salt; friction taken as tan 35 degrees |
| Allowance to loosen and lift the harvest layer | 300 N per metre of blade | Estimate; to be measured with the partner (PRB open questions) |
| Skids on wet salt | friction 0.30 | UHMW-PE on a wet crystalline surface |
| Back tension from the far capstan | 200 N | Enough to keep the rake square |
| Efficiencies | roller 0.98, one spur stage 0.96, bearings 0.98 | Greased gears with some dust |
| People | two crankers at up to 120 N; 30 turns a minute under load, 50 on the return | R2; sustained cranking |
| Moving to the next strip | 8 min | Unchain, slide both capstans 3 m, move the rollers, re-anchor |
| Crew | four | Two cranking near, one at the far capstan, one with rollers and ropes |
| Rope | 12 mm polyester double braid, 27 kN minimum breaking strength, splices 85 % | Catalogue class; certificate to confirm |
| Steels | C45 yield 340 MPa; S275 yield 275 MPa | Normalised bar; structural plate |
| FRP beam | flexural strength 200 MPa, modulus 23 GPa | Lower-bound pultruded values |
| Soil behind the bund | firm clay, undrained shear strength 50 kPa; helix bearing factor 9 | To confirm by a pull test on site |
| Brake lining | friction 0.30 | Woven lining on steel, dusty |
| Design pan | 30 m between bund crests | Assumption, to be surveyed |

## A. Drag on the rake (R2, R3)

The rake is sized so that its design drag with a full heap matches the rated 3 kN pull.

- Full heap: a 300 mm blade holds a heap of triangular section, 0.0643 m² over 3.0 m, or 0.19 m³ [A1], about 231 kg [A2].
- Sliding the full heap over the bed: 0.70 x 231 kg x 9.81 = 1,589 N [A3].
- Loosening and lifting the harvest layer: 300 N/m x 3.0 m = 900 N [A4].
- Skids: the rake weighs 40.4 kg [A5] and carries two ballast bags of 23.8 kg each [A5b]; 0.30 x 88 kg x 9.81 = 259 N [A6].
- Design drag 2,748 N [A7]; with the roller loss and 200 N of back tension the rope pull at the drum is 3,004 N [A8], equal to the rated 3 kN.

If the measured drag is higher, the skids are raised to take a thinner layer, the heap is smaller, or the rake is shortened; the capstan itself has margin (Section B).

## B. Capstan: crank force, pull and speed (R2, R3, R12)

- Gear ratio 84 to 14, 6 to 1 [B1]. At the end of a 30 m pass the rope is on its third layer, at 110.9 mm radius [B2].
- Crank force at the design drag: 3,004 N x 0.1109 m / (6 x 0.94) / (2 x 0.33 m) = 89 N per handle [B3]; R2 asks for 120 N or less.
- Pull from two people at 120 N: 4,030 N on the third layer [B4] and 3,685 N on a full fourth layer [B5]; R3 asks for 3 kN.
- Rope speed at 30 crank turns a minute: 0.053 m/s, about 3.1 m/min [B6]; each cranker works at 84 W [B7].
- Rope stored: 58 m in four layers of 22 turns [B8], with 38 mm of flange above the fourth layer [B9], which is more than two rope diameters. R12 asks for 45 m.

## C. Strength at twice the rated pull (R3, R10, R11)

*Table 2. Strength checks at 6 kN rope pull.*

| Part | Load case | Stress or force | Margin |
| --- | --- | --- | --- |
| Drum shaft, 40 mm C45 | Rope load mid-span between bearings 452 mm apart, plus torque on a full drum | 147 MPa combined [C1] | 2.3 on yield [C1b] |
| Crank shaft, 25 mm C45 | Tooth force on the pinion, 45 mm outside the bearing, plus torque | 161 MPa [C2] | 2.1 [C2b] |
| Pinion teeth, module 4, 35 mm face | Lewis bending, 14 teeth | 139 MPa [C3] | 2.5 [C3b] |
| Pawl and its boss | 7.8 kN at the tooth [C4]; 40 mm boss welded to the cheek, 52 mm long | 59 MPa [C5] | 4.7 [C5b] |
| Brake band | 247 degrees of wrap [C6] | 92 N on the lever holds the rated pull [C7] | R11 asks for 150 N or less |
| Rope | 3 kN rated pull, splices at 85 % | 27 kN breaking strength | 7.7 working-load factor [C8] |
| Chains, 8 mm grade 30 | Two chains at 23 degrees down to the anchors | 3.26 kN each [C9] | 2.4 on working load limit [C9b] |
| Ground anchors, 150 mm helix | Firm clay, 50 kPa | 7.95 kN holding each [C10] | 2.4 on the chain force [C10b] |
| Rake beam, FRP 100 x 100 x 6 | Heap and layer load along 3 m, pulled at both ends | 28 MPa [C13] | 7.1 [C13b]; bows 11 mm at the rated load [C14] |

The pawl was first drawn on a plain 16 mm pin cantilevered from the cheek; at 6 kN that pin would have bent (about 580 MPa), so the constructable design carries the pawl on a 40 mm boss welded to the cheek with an M24 bolt through it (SDG-DDR-002).

Tipping: the capstan weighs 102 kg without its anchors [C11]. With the rope leaving the top of the drum at 677 mm and the chains fixed at 650 mm, the resisting moment about the front tips of the runners is 1.55 times the tipping moment at the rated pull [C12].

> **Safety:** These margins hold only with certified rope, chain and shackles of the stated sizes, anchors that pass their on-site proof load, and parts made from the stated steels. Each is a safety stop in the build plan.

## D. Floor, lift-off near the bund, rate and set-up (R1, R4, R5, R8)

- Floor: with the ballast the skids press on the floor at 10.7 kPa [D1], less than a person standing; the blade edge stays 10 mm above the floor [D2] and no steel touches the pan.
- Lift-off near the bund: the rope comes down from the roller top, 156 mm above the crest, to the bridle swivel 130 mm above the floor. As the rake nears the bund the rope steepens, and once its upward pull exceeds the rake's weight the blade lifts and the heap is left behind. Without ballast this happens with the blade 5.9 m from the bund toe [D3]; with two 24 kg bags of salt it moves in to 3.3 m [D4]. The windrow therefore lies about 3.3 m from the toe, and loading it out uses existing methods.
- One strip: winding a 30 m pass 9.5 min [D5], winding the empty rake back 5.7 min [D6], moving 8 min; 23.2 min in all [D7].
- Gathering rate: one full heap per strip gives about 598 kg/h [D8], or 150 kg per worker-hour for a crew of four [D9]. R5 compares this with the dantala on the same pan; that baseline is not yet measured, so R5 is not verified.
- Set-up per crew, both crews working at once: carry the capstan into place 5 min, two anchors 6 min, chains 2 min, roller 1 min, rope round the pan to the rake 5 min: 19 min [D10], just inside R8.

## E. Mass and cost (R6, R9)

- Heaviest single part: a ballast bag at 23.8 kg, filled on site [E1]; the heaviest made parts are the drum (21.3 kg) and a side frame (20.9 kg). An assembled capstan weighs 102 kg; it is slid along the bund on its runners and is taken apart for moves between pans.
- Parts cost of the full set: USD 2,803 [E2]. Value-engineering target: USD 4,000. Estimated cost of the constructable design: USD 2,803 (USD 1,197 under the target) [E3].

## F. Results against every requirement

*Table 3. Results against SDG-REQ-001.*

| ID | Target | Result | Status |
| --- | --- | --- | --- |
| R1 | No worker enters the pan | Crews on dry ground; rake re-aligned by the return pull | Met by design |
| R2 | 120 N or less per handle | 89 N [B3] | Met |
| R3 | 3 kN from two people at 120 N; margin 2 at 6 kN | 4.0 and 3.7 kN [B4], [B5]; lowest margin 2.1 [C2b] | Met |
| R4 | Edge 5 to 25 mm up; no steel in the pan; 15 kPa or less | 10 mm; 10.7 kPa [D1], [D2] | Met by design |
| R5 | At least the dantala rate | 150 kg per worker-hour [D9]; no baseline | **Not verified** |
| R6 | Heaviest part 25 kg or less | 23.8 kg [E1] | Met |
| R7 | One season in brine | Material choice | Met by design |
| R8 | 20 min or less | 19 min [D10] | Met, small margin |
| R9 | Value-engineering target USD 4,000 | USD 2,803 [E2] | USD 1,197 under the target |
| R10 | Working-load factor 5 or more | 7.7 [C8] | Met |
| R11 | Pawl 6 kN; brake 150 N or less; anchors 1.5 times their share | 4.7, 92 N, 2.4 [C5b], [C7], [C10b] | Met on paper; soil to confirm |
| R12 | 45 m of rope per drum | 58 m [B8] | Met |

## Checks against the TRL 2 figures

The scaffold set a 3 kN pull (R3) before any drag estimate; the drag estimate here lands on it, which fixed the rake at 3.0 m and the blade at 300 mm. The scaffold had no figure for the windrow position; the lift-off calculation added the ballast bags and moved the windrow from the bund edge to about 3.3 m out (SDG-DDR-002).

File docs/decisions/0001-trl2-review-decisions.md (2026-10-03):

---
doc_id: SDG-DDR-001
title: SaltDrag TRL 2 review decisions
project: SaltDrag
doc_type: Design decision record
version: "0.1"
status: Draft
date: '2026-10-03'
author: Amish Chadha
license: CERN-OHL-S-2.0
revisions:
- version: "0.1"
  date: '2026-10-03'
  author: Amish Chadha
  change: TRL 2 review decisions, made under Amish's 2026-10-03 pre-approval of the batch
---

# 0001: TRL 2 review decisions

- **Date:** 2026-10-03
- **Status:** accepted. Decided by Amish under his pre-approval of 2026-10-03: "start with the first 14 repos from the list of 29 projects. I pre-approve the batch runs along with any recommendations you come up with. I also accept any cost overruns or variations from the assumed scope cost."

## Context

The scaffold (TRL 1, 2026-09-30) left the concept open on how the capstans stand and are anchored, the drive, the rope, the rake build and the people who would host a trial. Taking the repo to TRL 2 and on to TRL 3 in one run needed each of these settled. Amish pre-approved every recommendation for this batch, so each choice below is recorded as decided; safety choices take the conservative option and say what evidence would relax them.

## Options considered and decisions

*Table 1. Decisions at the TRL 2 review.*

| # | Question | Options | Decision | Reason |
| --- | --- | --- | --- | --- |
| D1 | Kind of capstan | Warping capstan with a person tailing the rope; geared drum winch that stores the rope | Geared drum winch, still called a hand capstan | Nobody holds a loaded rope by hand; simpler and safer for a small crew (conservative) |
| D2 | Where the capstan stands | On the bund crest; on dry ground behind the bund with a roller on the crest | Behind the bund, drum 1.5 m behind the crest centre, with a bund roller saddle on the crest | A 0.4 m crest cannot carry a capstan and two people cranking; the roller keeps the rope off the bund |
| D3 | Drive | Worm gear; two-stage spur; single-stage spur | Single spur stage, module 4, 84 and 14 teeth (6 to 1), two 330 mm cranks set 180 degrees apart | Efficient, repairable, gears can be bought cut in India; meets R2 with margin |
| D4 | Rope | Nylon; polypropylene; polyester; high-modulus polyethylene | 12 mm polyester double braid, 45 m per side | Low stretch limits snap-back energy; UV and brine tolerant; affordable (nylon stores too much energy; polypropylene degrades in sun) |
| D5 | Rake | Bolted sections; one piece; timber | One-piece 3.0 m FRP box beam with a 300 mm UHMW-PE blade | Light (12.8 kg beam), does not rust, carried by two people; width set by the 3 kN design drag |
| D6 | Blade height | Fixed; adjustable skids | Three UHMW-PE skids on slotted stainless hangers; blade 10 mm above the floor, adjustable 5 to 25 mm | Protects the hand-hardened floor (R4) |
| D7 | Anchoring | Stakes; deadweight; screw-in ground anchors | Two screw-in helical anchors per capstan, chained to ears on the side frames at rope height | Holds 3 kN without ballast; quick to move; chain at rope height stops tipping |
| D8 | Materials | Painted steel; galvanised steel; stainless throughout | Hot-dip galvanised steel on dry ground; FRP, UHMW-PE and 316 stainless in the pan; stainless-insert thermoplastic bearings; daily freshwater rinse | Nothing that rusts sits in brine (R7) at a moderate cost |
| D9 | Holding and paying out (safety) | Pawl only; brake only; pawl and brake | Pawl always engaged while winding; paying out only on the band brake with the crank handles removed | Conservative: a released crank cannot spin back. Relaxing it (cranks left on while paying out) would need a self-sustaining brake or a no-back crank tested with CalRig |
| D10 | Snap-back protection (safety) | Rope choice only; dampers and exclusion zone | Low-stretch rope plus a weighted damper bag on each loaded rope, and a 2 m exclusion zone along the rope line | Conservative; a test of rope behaviour at break with CalRig would show whether the zone can be narrowed |
| D11 | Anchor proof load (safety) | Trust the estimate; proof-load on site | Every anchor proof-loaded on site to 1.5 times its share of the rated pull before first use | Soil behind the bunds is unknown; a site pull test is the only evidence |
| D12 | Design pan | 20 m; 30 m; 45 m | 30 m between bund crests, rope for 45 m | Covers the pans described as tens of metres wide; survey to confirm |
| D13 | Crew | Three; four | Four: two cranking, one at the far capstan, one moving rollers and ropes | Keeps cranking shifts short in the heat |
| D14 | Co-design partner | Producer organisations and NGOs working with Agariyas | First candidate to approach: SEWA (Self Employed Women's Association), which works with salt-farming families in the Little Rann | Women-led and already working on livelihoods in the pans. Not agreed |
| D15 | First trial region | Little Rann of Kutch; coastal Kutch creeks | Little Rann of Kutch, first candidate | Where the problem was found and the users are |
| D16 | Machine-use condition | Assume hand tools are allowed; ask first | Ask the forest department in writing, through the partner, before any trial | The registration conditions forbid machine use; a written answer removes the doubt |
| D17 | Shared hand capstan block | Separate designs; share | SaltDrag's capstan offered as the first candidate for the common block with SiltHaul | One proven capstan for both; SiltHaul is not changed here |

## Consequences

- The concept gains a bund roller saddle (BOM 12) and loses the windrow board; ballast bags follow from the lift-off calculation (SDG-DDR-002).
- R10 to R12 are added to SDG-REQ-001 for rope safety, holding and rope capacity.
- The site facts the decisions rest on (crest width, ground behind the bunds, soil strength, drag per metre) are listed in SDG-DEC-001 to be confirmed.
- `budget_usd` in `project.yaml` is unchanged; the estimated cost is reported against it as a value-engineering target.

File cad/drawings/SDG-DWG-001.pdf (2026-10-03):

CONCEPT, NOT FOR FABRICATION | SaltDrag · github.com/BoujeeEnjinia1701/saltdrag

FRONT VIEW
Scale 1:20; looking at the front (along +Y)

TOP VIEW
Scale 1:20; looking down (along -Z)

RIGHT VIEW
Scale 1:20; looking at the right side (along -X)

930

900 1062

DRUM (3)

GEAR UNDER GUARD (4, 10)

SIDE FRAME (1)

CROSS TUBES (2)

CRANKS (9), R330

ANCHOR EAR, 22 HOLE

ROPE LEAVES DRUM TOP TOWARD PAN (-Y)


WORKING LAYOUT
Seen from the front right and above; pan shortened to 7 m

MAIN DIMENSIONS AND INTERFACES (MM)
Gear pair module 4, 84 and 14 teeth, ratio 6:1, centres 196 Drum barrel 168.3 OD x 280; flanges 330; shaft 40 C45
Rope 12 polyester; 58 m in 4 layers; freeboard 38
Bearings 4-bolt flange, 40 and 25 bore, stainless insert
Ratchet 200 OD, 20 teeth; pawl on 40 boss; band brake on 330 rim Side frames 6 plate on 40 SHS runners 900 long, 406 apart Anchors: 2 chains from ears to helical anchors 1700 behind
Rake: FRP 100 x 100 x 6 beam 3,000; UHMW blade 300 tall Rake: blade edge 10 above floor on 3 skids (5 to 25) Bridles from end-cap eyes; apex 2,000 ahead of blade Bund roller 100 x 200 UHMW, top 150 above crest Capstan drum 1,500 behind the crest centre
Drum axis 560 and crank axis 756 above the ground Third-angle; front view from the pan side; (n) = BOM line
REV | DESCRIPTION | DATE | BY
P1 | Preliminary GA for TRL 3 (from cad/src/model.py) | 2026-10-03 | AC
P2 | SDG-DDR-002: design for construction | 2026-10-03 | AC
SALTDRAG | github.com/BoujeeEnjinia1701/saltdrag

## Hand capstan and rake set: general arrangement

DRAWING NO.
SDG-DWG-001

REV
P2

SHEET
1 of 1

SIZE

## ANSI B

SCALE
1:20

UNITS
mm
PROJECTION | DATE
2026-10-03

DRAWN
Amish Chadha

MATERIAL / NOTES
Galvanised steel capstan; FRP and UHMW-PE rake; per bom/bom.csv. PRELIMINARY, NOT FOR FABRICATION
Licensed CERN-OHL-S-2.0 · Design Molecule Lab · designmolecule.com | Generated from cad/src; do not edit by hand

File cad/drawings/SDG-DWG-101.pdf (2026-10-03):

### BUILD PLAN SKETCH, PLAN NOT YET BUILT SaltDrag · github.com/BoujeeEnjinia1701/saltdrag

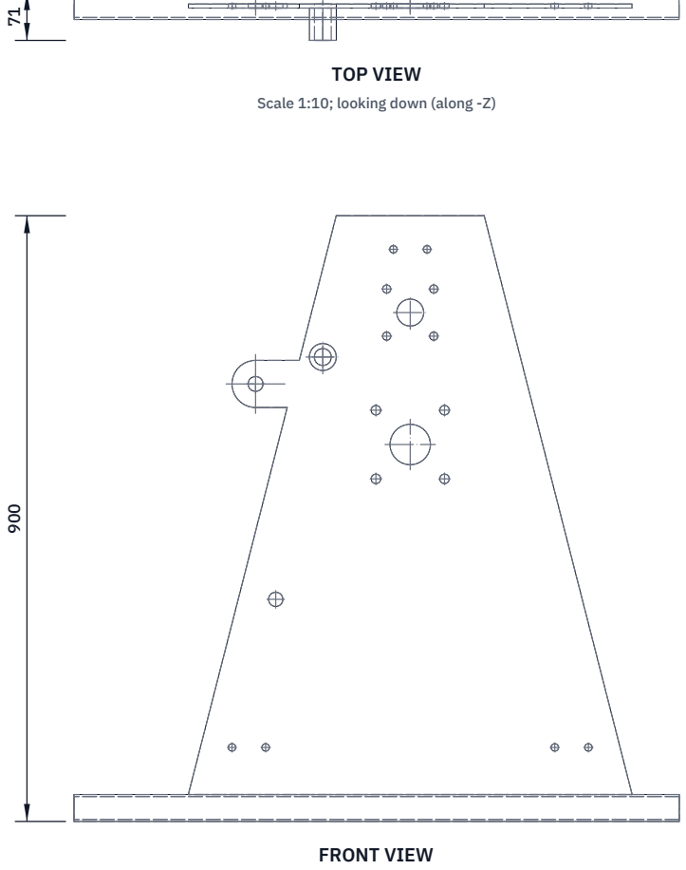
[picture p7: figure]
FRONT VIEW; TOP VIEW; Scale 1:10; looking down (along -Z)

Scale 1:10; looking at the front (along +Y)

RIGHT VIEW
Scale 1:10; looking at the right side (along -X)

900

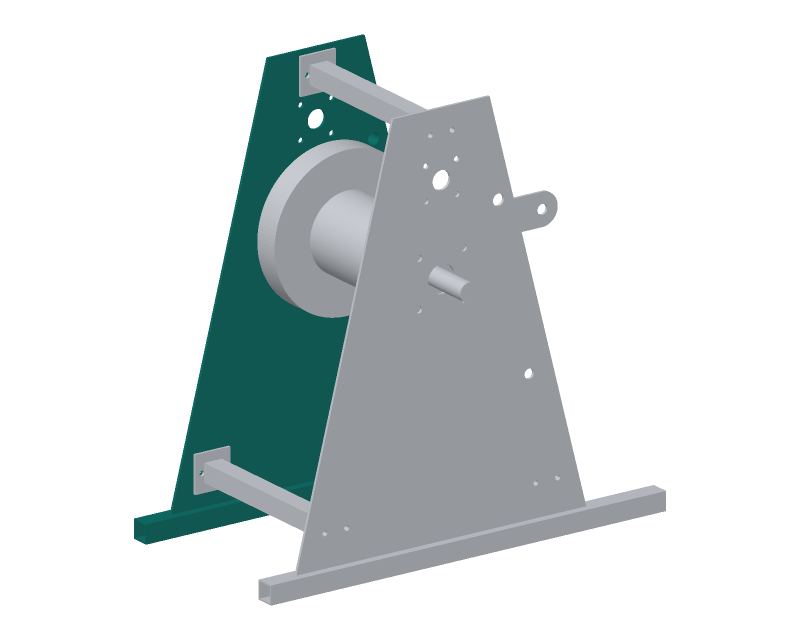
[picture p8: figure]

WHERE IT GOES
This part in colour, its neighbours in grey

HOW TO MAKE IT AND HOW IT FITS
Make 4: two per capstan. Left frames also get the pawl boss. Cheek: 6 mm plate, 660 wide at the base, 220 at the top, 860 tall; base edge 40 mm up (it sits on the runner).
Ear at the rear: 70 mm tall, round end R35, 22 mm hole 230 behind the drum centre line and 650 mm above the ground.
Drum hole 60 mm at 560 mm up; crank shaft hole 40 mm at 756 mm up. Bearing bolts: 14 mm holes on a 102 square (drum), 12 mm on a 70 square (crank shaft), centred on each hole.
Cross tube bolts: 11 mm pairs 50 apart at the three tube positions. Pawl bolt 25 mm at 130 back, 690 up; brake pivot 21 mm at 200 back, 330 up. Drill both in all four frames.
Runner: SHS 40 x 40 x 3, 900 long, 400 ahead of and 500 behind the drum centre. Weld the cheek on its centre line, both sides.
Left frames: weld a 40 OD, 24 bore boss 52 long on the outside over the pawl hole. Galvanise after welding and drilling.
Check: the drum and crank shaft holes of a pair line up on a rod.
REV | DESCRIPTION | DATE | BY
P1 | Making sketch for the prototype build plan | 2026-10-03 | AC
SALTDRAG | github.com/BoujeeEnjinia1701/saltdrag

## SaltDrag capstan side frame (make 4): making sketch

DRAWING NO.
SDG-DWG-101

REV
P1

SHEET
1 of 1

SIZE

## ANSI B

SCALE
1:10

UNITS
mm
PROJECTION | DATE
2026-10-03

DRAWN
Amish Chadha

MATERIAL / NOTES
S275 steel plate 6 mm and SHS 40 x 40 x 3 mm; hot-dip galvanised
Licensed CERN-OHL-S-2.0 · Design Molecule Lab · designmolecule.com | Generated from cad/src; do not edit by hand

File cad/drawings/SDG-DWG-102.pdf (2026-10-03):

### BUILD PLAN SKETCH, PLAN NOT YET BUILT SaltDrag · github.com/BoujeeEnjinia1701/saltdrag

FRONT VIEW
Scale 1:5; looking at the front (along +Y)

TOP VIEW
Scale 1:5; looking down (along -Z)

RIGHT VIEW
Scale 1:5; looking at the right side (along -X)

400

80 80

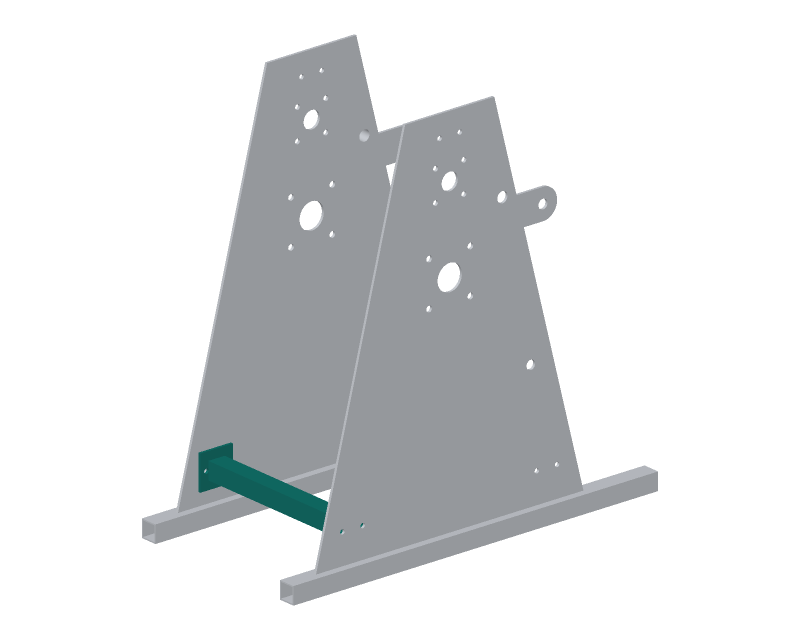
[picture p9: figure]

WHERE IT GOES
This part in colour, its neighbours in grey

HOW TO MAKE IT AND HOW IT FITS
Make 6: three per capstan, all the same.
Tube: SHS 40 x 40 x 3 mm, 382 mm long, ends square.
End plates: 80 x 80 x 6 mm, two per tube, welded on centre so
the length over both plates is 394 mm (the gap between cheeks). Two 11 mm holes in each plate, 25 mm each side of the tube centre, on the horizontal centre line.
Weld all round; grind the weld flush on the outer faces.
Galvanise; run a drill through the holes after galvanising.
Fit: plates sit flat on the inner faces of the cheeks, two
M10 bolts each end. Positions: front low (240 ahead, 110 up), rear low (240 behind, 110 up) and top (over the drum, 850 up). Check: 394 mm over the plates, within 1 mm, plates parallel.
REV | DESCRIPTION | DATE | BY
P1 | Making sketch for the prototype build plan | 2026-10-03 | AC
SALTDRAG | github.com/BoujeeEnjinia1701/saltdrag

## SaltDrag capstan cross tube (make 6): making sketch

DRAWING NO.
SDG-DWG-102

REV
P1

SHEET
1 of 1

SIZE

## ANSI B

SCALE
1:5

UNITS
mm
PROJECTION | DATE
2026-10-03

DRAWN
Amish Chadha

MATERIAL / NOTES
SHS 40 x 40 x 3 mm and plate 6 mm, S275; hot-dip galvanised
Licensed CERN-OHL-S-2.0 · Design Molecule Lab · designmolecule.com | Generated from cad/src; do not edit by hand

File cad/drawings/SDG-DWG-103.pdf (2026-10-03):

### BUILD PLAN SKETCH, PLAN NOT YET BUILT SaltDrag · github.com/BoujeeEnjinia1701/saltdrag

FRONT VIEW
Scale 1:5; looking at the front (along +Y)

TOP VIEW
Scale 1:5; looking down (along -Z)

RIGHT VIEW
Scale 1:5; looking at the right side (along -X)

592

330 330

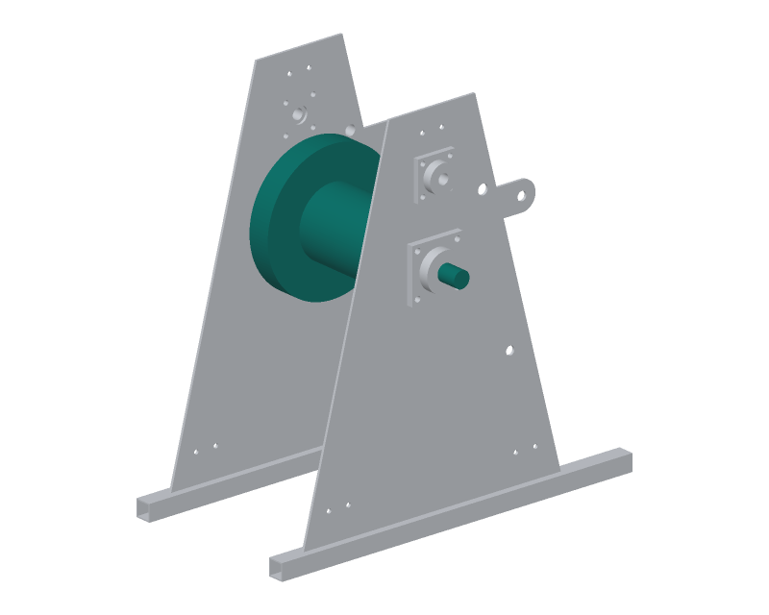
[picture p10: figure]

WHERE IT GOES
This part in colour, its neighbours in grey

HOW TO MAKE IT AND HOW IT FITS
Make 2. Barrel: pipe 168.3 OD x 4.5 wall, 280 long, ends square. Flanges: two discs 330 OD, 6 mm plate, 40.5 mm centre hole. Rope hole: 14 mm in the right flange, 94 mm above the centre. Brake rim: 50 x 6 flat bar rolled to 330 OD, butt welded, welded to the outside face of the left flange, flush with its edge.
Shaft: C45 (EN8) bright bar 40 mm, 592 long. The right flange's outer face is 185 mm right of the shaft centre (its middle).
Weld flanges to barrel all round; weld shaft to both flanges.
Keyways 12 mm wide, 40 long at both ends for the gear and ratchet. Turn the brake rim true on the shaft after welding (0.5 mm). Galvanise barrel and flanges; mask and grease the shaft ends.
Fit: the shaft runs in the 40 mm flange bearings; 15 mm gap to
the right cheek, 43 mm to the left. Mass about 21 kg.
Check: spin it on the shaft; the rim runs true within 0.5 mm.
REV | DESCRIPTION | DATE | BY
P1 | Making sketch for the prototype build plan | 2026-10-03 | AC
SALTDRAG | github.com/BoujeeEnjinia1701/saltdrag

## SaltDrag capstan drum (make 2): making sketch

DRAWING NO.
SDG-DWG-103

REV
P1

SHEET
1 of 1

SIZE

## ANSI B

SCALE
1:5

UNITS
mm
PROJECTION | DATE
2026-10-03

DRAWN
Amish Chadha

MATERIAL / NOTES
Pipe 168.3 x 4.5 mm, plate 6 mm, flat bar 50 x 6 mm, C45 bar 40 mm
Licensed CERN-OHL-S-2.0 · Design Molecule Lab · designmolecule.com | Generated from cad/src; do not edit by hand

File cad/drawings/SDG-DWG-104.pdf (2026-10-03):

### BUILD PLAN SKETCH, PLAN NOT YET BUILT SaltDrag · github.com/BoujeeEnjinia1701/saltdrag

FRONT VIEW
Scale 1:5; looking at the front (along +Y)

TOP VIEW
Scale 1:5; looking down (along -Z)

RIGHT VIEW
Scale 1:5; looking at the right side (along -X)

690

63 64

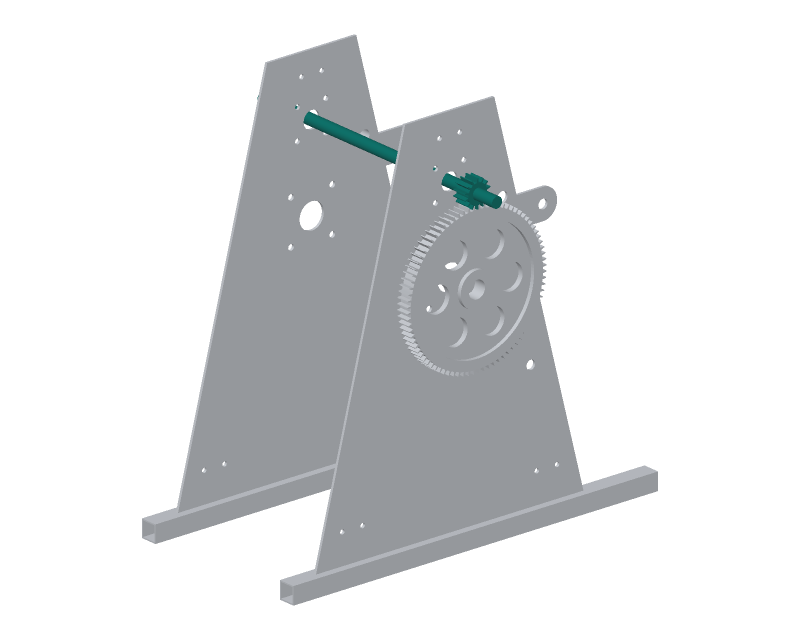
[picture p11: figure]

WHERE IT GOES
This part in colour, its neighbours in grey

HOW TO MAKE IT AND HOW IT FITS
Make 2. Shaft: C45 bright bar 25 mm, 690 long, ends chamfered. Keyway 8 mm wide, 40 long, for the pinion, from 253 to 289 mm right of the shaft middle.
Cross-pin holes 8 mm through, 20 mm in from each end, for the crank hub pins.
Pinion: bought, module 4, 14 teeth, 35 face, bored 25, keyed and held by a set screw. Its teeth line up with the gear's face.
Fit: the shaft runs in two 25 mm flange bearings on the cheeks, 756 mm above the ground and 196 mm above the drum centre. The pinion sits outside the right bearing, inside the guard. Check: the shaft turns by hand in its bearings with the pinion meshing the gear; a feeler shows backlash of 0.2 to 0.5 mm.
REV | DESCRIPTION | DATE | BY
P1 | Making sketch for the prototype build plan | 2026-10-03 | AC
SALTDRAG | github.com/BoujeeEnjinia1701/saltdrag

## SaltDrag crank shaft with pinion (make 2): making sketch

DRAWING NO.
SDG-DWG-104

REV
P1

SHEET
1 of 1

SIZE

## ANSI B

SCALE
1:5

UNITS
mm
PROJECTION | DATE
2026-10-03

DRAWN
Amish Chadha

MATERIAL / NOTES
C45 (EN8) bright bar 25 mm; bought pinion, module 4, 14 teeth
Licensed CERN-OHL-S-2.0 · Design Molecule Lab · designmolecule.com | Generated from cad/src; do not edit by hand

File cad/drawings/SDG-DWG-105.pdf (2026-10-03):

### BUILD PLAN SKETCH, PLAN NOT YET BUILT SaltDrag · github.com/BoujeeEnjinia1701/saltdrag

FRONT VIEW
Scale 1:5; looking at the front (along +Y)

TOP VIEW
Scale 1:5; looking down (along -Z)

RIGHT VIEW
Scale 1:5; looking at the right side (along -X)

160

210 331

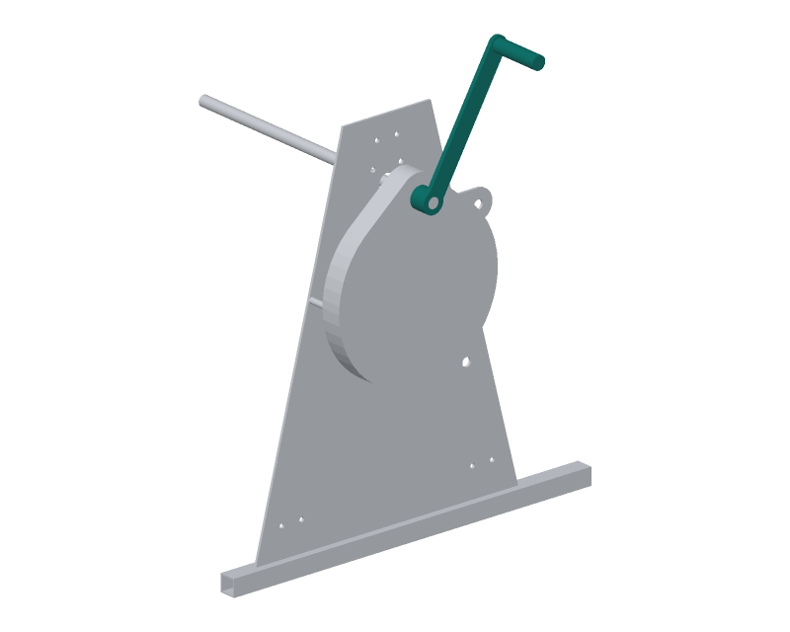
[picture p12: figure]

WHERE IT GOES
This part in colour, its neighbours in grey

HOW TO MAKE IT AND HOW IT FITS
Make 4: a right and a left handle per capstan (mirror images). Hub: 50 OD, 40 long, bored 25 for the shaft; 8 mm cross-pin hole 20 mm from the inner end. The hub slides on the shaft end.
Arm: flat bar 40 x 10, 330 mm between the shaft and grip centres, ends rounded R20; welded to the outer end of the hub.
Grip: 32 mm tube 120 long turning on a 16 mm pin welded to the arm; washer and split pin on the outer end.
On the capstan the two handles sit 180 deg apart, so one person pushes while the other pulls.
Galvanise; grease the grip pin.
Fit: hub against the shaft shoulder; cross pin and R-clip hold it. Handles come off before any paying out under load.
Check: the grip spins freely; the hub cannot slide off with the pin in.
REV | DESCRIPTION | DATE | BY
P1 | Making sketch for the prototype build plan | 2026-10-03 | AC
SALTDRAG | github.com/BoujeeEnjinia1701/saltdrag

## SaltDrag crank handle (make 4): making sketch

DRAWING NO.
SDG-DWG-105

REV
P1

SHEET
1 of 1

SIZE

## ANSI B

SCALE
1:5

UNITS
mm
PROJECTION | DATE
2026-10-03

DRAWN
Amish Chadha

MATERIAL / NOTES
Steel tube 50 x 12.5, flat bar 40 x 10, tube 32 OD, pin 16; galvanised
Licensed CERN-OHL-S-2.0 · Design Molecule Lab · designmolecule.com | Generated from cad/src; do not edit by hand

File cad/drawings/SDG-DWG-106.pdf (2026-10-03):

### BUILD PLAN SKETCH, PLAN NOT YET BUILT SaltDrag · github.com/BoujeeEnjinia1701/saltdrag

FRONT VIEW
Scale 1:5; looking at the front (along +Y)

TOP VIEW
Scale 1:5; looking down (along -Z)

RIGHT VIEW
Scale 1:5; looking at the right side (along -X)

106

250 250

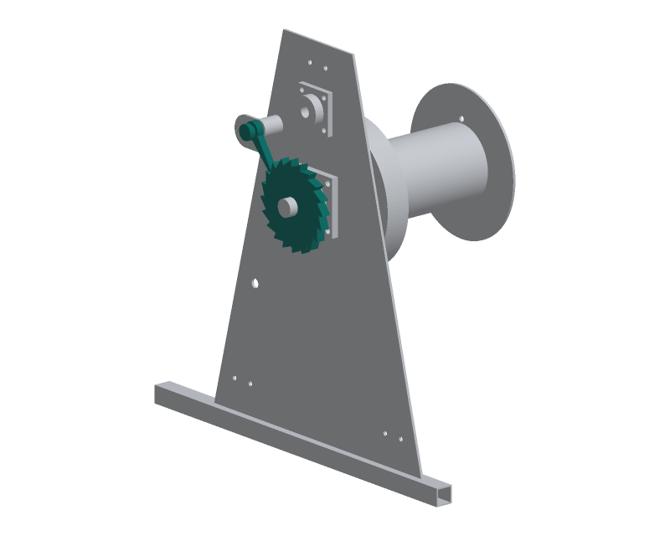
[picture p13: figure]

WHERE IT GOES
This part in colour, its neighbours in grey

HOW TO MAKE IT AND HOW IT FITS
Wheel: 200 OD, 20 teeth, 20 mm C45 plate. Each tooth rises 14 mm along the circle and drops straight back to the root. Bore 40 with a 12 mm keyway; set screw M10 in the hub side. Pawl: 16 mm C45 plate, 25 wide at the pivot (40 OD round end), 8 wide at the tip; 25 mm pivot hole; harden the tip.
Pivot: M24 bolt through the pawl, the 40 mm boss and the cheek, nyloc nut inside. Pivot 130 behind and 130 above the drum centre. Spring: stainless return spring from the pawl to a 6 mm hole in the cheek ear, so the pawl always drops into the teeth.
The pawl lets the drum wind rope in and stops it running back. Fit: the wheel goes on the drum shaft outside the left bearing, 10 mm clear of it; the pawl lies in the same plane.
Check: wind by hand; the pawl clicks into every tooth and holds.
REV | DESCRIPTION | DATE | BY
P1 | Making sketch for the prototype build plan | 2026-10-03 | AC
SALTDRAG | github.com/BoujeeEnjinia1701/saltdrag

## SaltDrag ratchet wheel and pawl (make 2 sets): making sketch

DRAWING NO.
SDG-DWG-106

REV
P1

SHEET
1 of 1

SIZE

## ANSI B

SCALE
1:5

UNITS
mm
PROJECTION | DATE
2026-10-03

DRAWN
Amish Chadha

MATERIAL / NOTES
C45 plate 20 mm (wheel) and 16 mm (pawl), laser or flame cut
Licensed CERN-OHL-S-2.0 · Design Molecule Lab · designmolecule.com | Generated from cad/src; do not edit by hand

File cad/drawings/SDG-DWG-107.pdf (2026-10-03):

### BUILD PLAN SKETCH, PLAN NOT YET BUILT SaltDrag · github.com/BoujeeEnjinia1701/saltdrag

FRONT VIEW
Scale 1:10; looking at the front (along +Y)

TOP VIEW
Scale 1:10; looking down (along -Z)

RIGHT VIEW
Scale 1:10; looking at the right side (along -X)

234

598 421

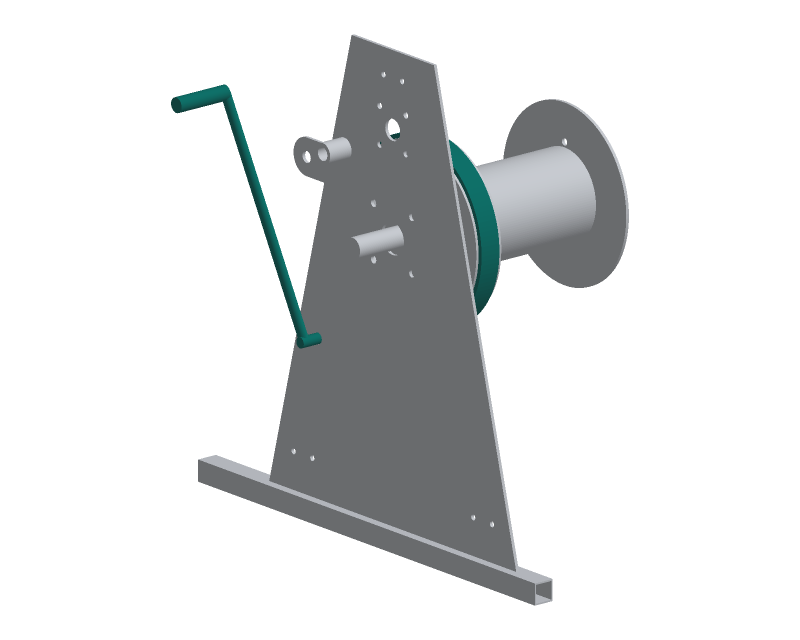
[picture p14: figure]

WHERE IT GOES
This part in colour, its neighbours in grey

HOW TO MAKE IT AND HOW IT FITS
Band: steel strip 40 x 3 mm, about 760 long, rolled to 340 ID;
woven brake lining 5 mm riveted inside with countersunk rivets.
The band wraps about 245 deg round the brake rim on the left flange, open toward the rear bottom.
Ends: a 10 mm link from each end. The upper end goes to the pivot pin; the lower end goes to the inner arm, 50 mm from the pivot. Pivot: 20 mm shaft through a 21 mm hole in the left cheek, 200 behind and 330 above the ground. Inner arm inside, lever outside. Lever: 25 mm bar, 450 long, rising at 62 deg toward the rear; grip at the top. Lifting the lever tightens the band.
A 92 N pull on the grip holds the rated 3 kN rope pull (estimate). Fit: lining 2 to 3 mm off the rim when the lever is down.
Check: lever up, the drum cannot be turned by hand at the rim.
REV | DESCRIPTION | DATE | BY
P1 | Making sketch for the prototype build plan | 2026-10-03 | AC
SALTDRAG | github.com/BoujeeEnjinia1701/saltdrag

## SaltDrag brake band and lever (make 2): making sketch

DRAWING NO.
SDG-DWG-107

REV
P1

SHEET
1 of 1

SIZE

## ANSI B

SCALE
1:10

UNITS
mm
PROJECTION | DATE
2026-10-03

DRAWN
Amish Chadha

MATERIAL / NOTES
Steel strip 40 x 3 with 5 mm woven lining; bar 25 and 20 mm
Licensed CERN-OHL-S-2.0 · Design Molecule Lab · designmolecule.com | Generated from cad/src; do not edit by hand

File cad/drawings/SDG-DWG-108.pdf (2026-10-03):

### BUILD PLAN SKETCH, PLAN NOT YET BUILT SaltDrag · github.com/BoujeeEnjinia1701/saltdrag

FRONT VIEW
Scale 1:10; looking at the front (along +Y)

TOP VIEW
Scale 1:10; looking down (along -Z)

RIGHT VIEW
Scale 1:10; looking at the right side (along -X)

94

400 446

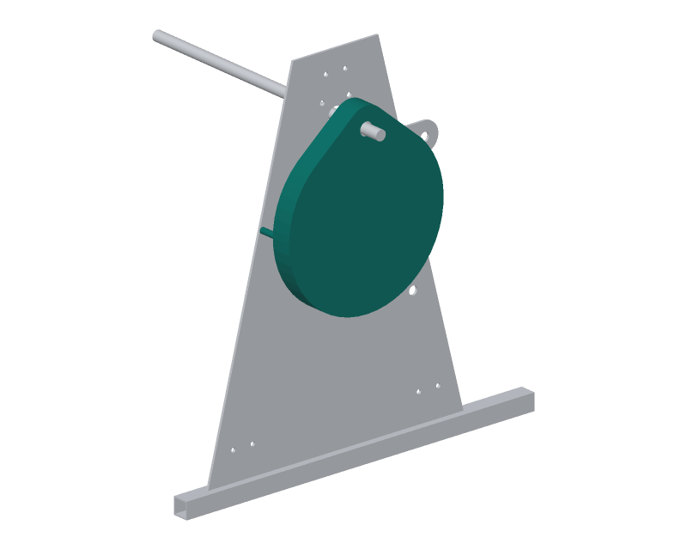
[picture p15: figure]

WHERE IT GOES
This part in colour, its neighbours in grey

HOW TO MAKE IT AND HOW IT FITS
Outline: a 400 mm circle round the gear centre joined by straight sides to a 100 mm circle round the crank shaft centre (196 above). Face: 2 mm sheet cut to the outline; 32 mm hole for the crank shaft. Rim: 2 mm strip 50 wide, rolled and welded round the face edge, so the guard is a cup 50 deep, open toward the cheek.
Spacers: three 14 OD tubes 44 long between the cheek and the cup edge, at the front, rear and bottom, 190 from the gear centre.
M8 bolts through cup, spacer and cheek (drill the cheek 9 mm). Paint bright yellow so the moving gears are marked.
Fit: 11 mm clear of the gear teeth, 3.5 mm round the crank shaft. Check: no finger can reach the gear mesh from outside the guard.
REV | DESCRIPTION | DATE | BY
P1 | Making sketch for the prototype build plan | 2026-10-03 | AC
SALTDRAG | github.com/BoujeeEnjinia1701/saltdrag

## SaltDrag gear guard (make 2): making sketch

DRAWING NO.
SDG-DWG-108

REV
P1

SHEET
1 of 1

SIZE

## ANSI B

SCALE
1:10

UNITS
mm
PROJECTION | DATE
2026-10-03

DRAWN
Amish Chadha

MATERIAL / NOTES
Steel sheet 2 mm, tube 14 OD spacers, M8 bolts; painted yellow
Licensed CERN-OHL-S-2.0 · Design Molecule Lab · designmolecule.com | Generated from cad/src; do not edit by hand

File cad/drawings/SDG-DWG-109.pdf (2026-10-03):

### BUILD PLAN SKETCH, PLAN NOT YET BUILT SaltDrag · github.com/BoujeeEnjinia1701/saltdrag

FRONT VIEW
Scale 1:5; looking at the front (along +Y)

TOP VIEW
Scale 1:5; looking down (along -Z)

RIGHT VIEW
Scale 1:5; looking at the right side (along -X)

316

300 180

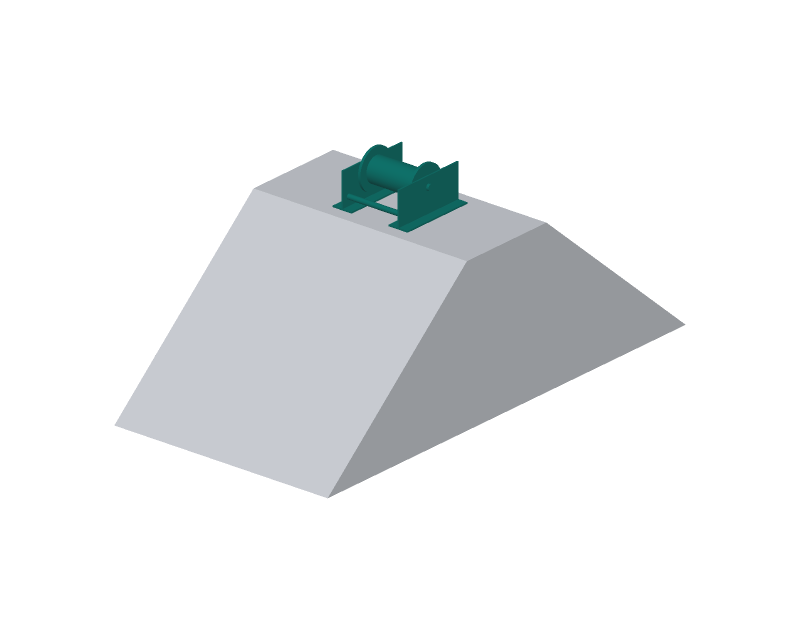
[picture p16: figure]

WHERE IT GOES
This part in colour, its neighbours in grey

HOW TO MAKE IT AND HOW IT FITS
Side plates: two, 6 mm, 300 long x 140 tall, with a 70 mm round boss at 100 up; 26 mm axle hole at its centre. 236 apart (centres).
Foot plates: 80 x 6 mm, 300 long, welded under each side plate.
Tie bars: two 20 mm round bars between the side plates, 120 ahead
of and behind the axle, 40 up. Weld, then galvanise.
Roller: UHMW-PE 100 OD x 200 long, 26 mm bore; two UHMW-PE flanges 160 OD x 10 bolted or pressed on the ends.
Axle: stainless 316, 25 mm, 260 long, R-clip holes 8 from each end.
The saddle sits astride the bund crest with the rope over the roller,
so the rope never cuts the bund. Roller top 150 above the crest. Fit: 5 mm clear between the flanges and the side plates.
Check: the roller spins freely; the feet sit flat on a board.
REV | DESCRIPTION | DATE | BY
P1 | Making sketch for the prototype build plan | 2026-10-03 | AC
SALTDRAG | github.com/BoujeeEnjinia1701/saltdrag

## SaltDrag bund roller saddle (make 2): making sketch

DRAWING NO.
SDG-DWG-109

REV
P1

SHEET
1 of 1

SIZE

## ANSI B

SCALE
1:5

UNITS
mm
PROJECTION | DATE
2026-10-03

DRAWN
Amish Chadha

MATERIAL / NOTES
S275 plate 6 mm, bar 20 mm, galvanised; UHMW-PE roller; 316 axle
Licensed CERN-OHL-S-2.0 · Design Molecule Lab · designmolecule.com | Generated from cad/src; do not edit by hand

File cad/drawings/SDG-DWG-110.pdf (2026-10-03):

### BUILD PLAN SKETCH, PLAN NOT YET BUILT SaltDrag · github.com/BoujeeEnjinia1701/saltdrag

FRONT VIEW
Scale 1:20; looking at the front (along +Y)

TOP VIEW
Scale 1:20; looking down (along -Z)

RIGHT VIEW
Scale 1:20; looking at the right side (along -X)

3000

100 100

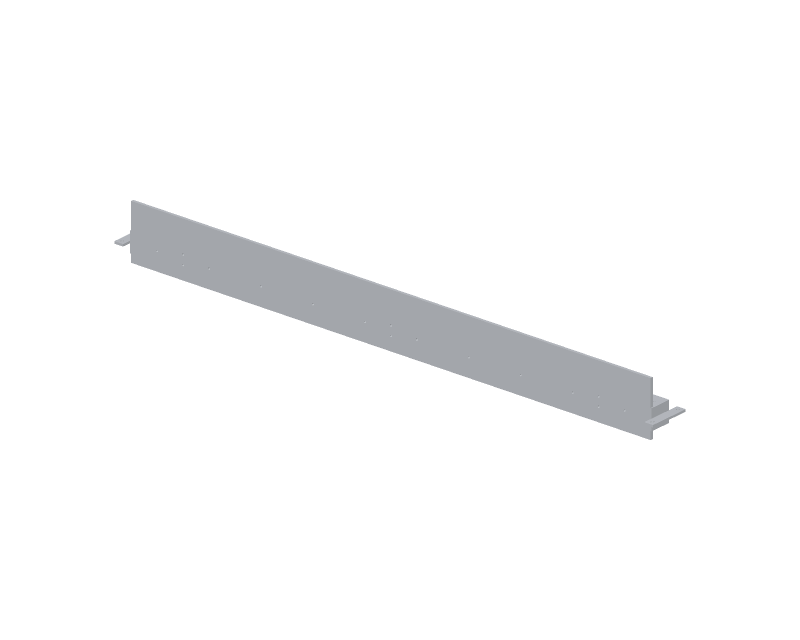
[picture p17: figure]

WHERE IT GOES
This part in colour, its neighbours in grey

HOW TO MAKE IT AND HOW IT FITS
One beam: FRP 100 x 100 x 6 mm square tube, cut to 3,000 mm. Mark a centre line on the front face. Positions are from the middle. Blade bolt holes, 11 mm through both walls, front to back,
110 mm above the floor line (50 above the beam's underside):
ten holes, 150 to 1,350 mm each side of the middle, 300 apart.
Skid hanger holes, 11 mm through, at the middle and 1,200 each side, 25 and 75 mm above the beam's underside.
End cap holes: 13 mm top to bottom, 74 and 114 mm in from each end, on the centre line.
Use a sharp HSS or carbide drill, slow, backed with wood; wear a
dust mask (glass fibre). Seal every cut end and hole with resin.
Fit: the blade bolts with stainless crush sleeves inside the tube. Check: lay the blade on the beam; all holes line up.
REV | DESCRIPTION | DATE | BY
P1 | Making sketch for the prototype build plan | 2026-10-03 | AC
SALTDRAG | github.com/BoujeeEnjinia1701/saltdrag

## SaltDrag rake beam: making sketch

DRAWING NO.
SDG-DWG-110

REV
P1

SHEET
1 of 1

SIZE

## ANSI B

SCALE
1:20

UNITS
mm
PROJECTION | DATE
2026-10-03

DRAWN
Amish Chadha

MATERIAL / NOTES
Pultruded FRP square tube 100 x 100 x 6 mm, 3,000 mm
Licensed CERN-OHL-S-2.0 · Design Molecule Lab · designmolecule.com | Generated from cad/src; do not edit by hand

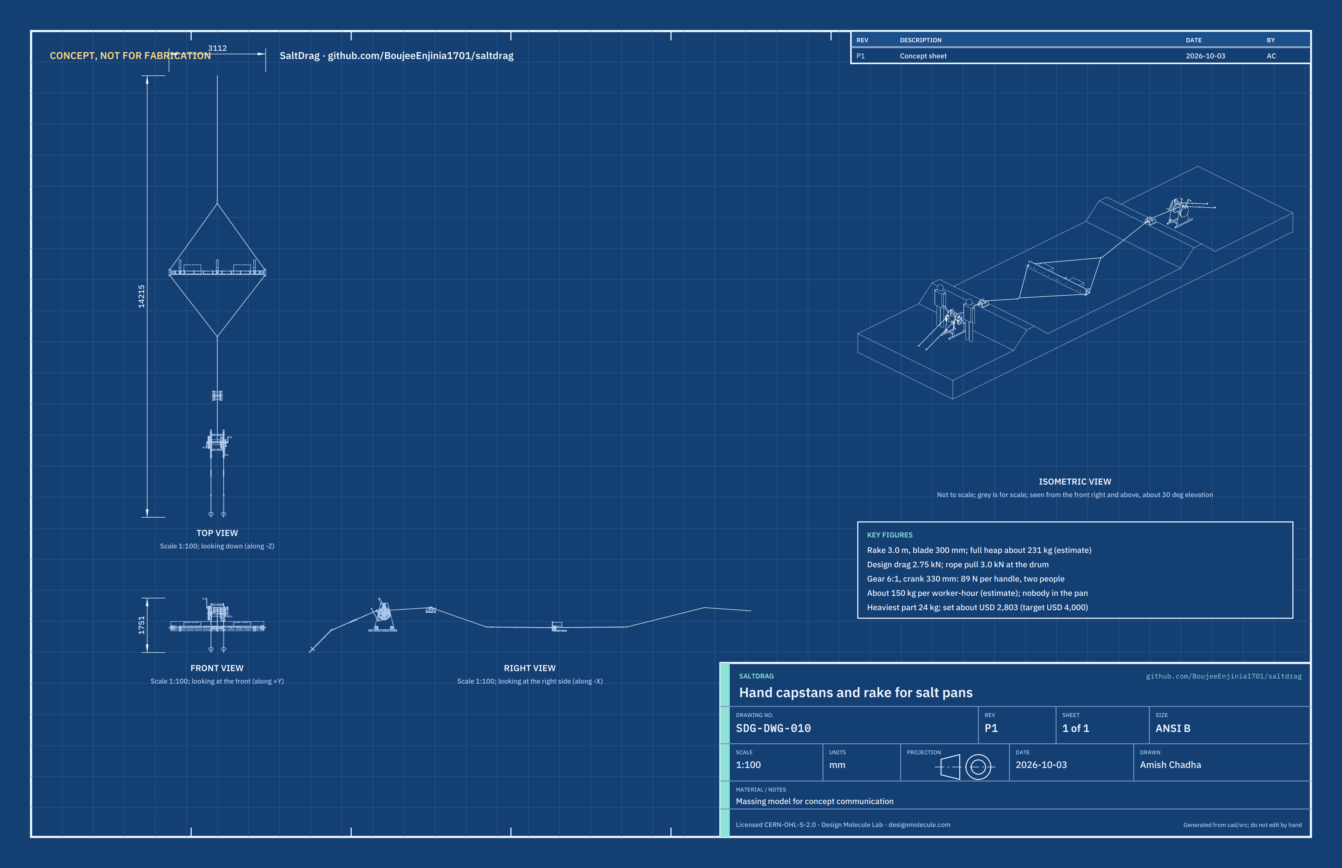
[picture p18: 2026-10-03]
media/concept-blueprint.png

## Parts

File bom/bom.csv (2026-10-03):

item | qty | spec | supplier | unit_cost_usd | make_buy | notes
1 Capstan side frame | 4 | 6 mm S275 steel plate cheek (trapezoid 660 mm base, 220 mm top, 860 mm tall) with an anchor ear, welded on a 40 x 40 x 3 mm SHS runner 900 mm long; holes for bearings, cross tubes, pawl and brake pivot; left frames carry a welded 40 mm pawl boss; hot-dip galvanised | Local fabricator (steel from a stockist in Gandhidham or Ahmedabad) | 55.00 | make | Two per capstan; 20.9 kg each (model); cut and drilled per SDG-DWG-101
2 Cross tube | 6 | 40 x 40 x 3 mm SHS, 382 mm, with two 80 x 80 x 6 mm end plates welded on, two 11 mm holes each; hot-dip galvanised | Local fabricator | 12.00 | make | Three per capstan (front low | rear low and top); SDG-DWG-102
3 Drum | 2 | Barrel 168.3 x 4.5 mm steel pipe 280 mm long; two 330 mm x 6 mm flanges; 50 x 6 mm brake rim ring on the left flange; 40 mm C45 (EN8) bright shaft 592 mm long welded through; 14 mm rope anchor hole; galvanised barrel and flanges, shaft ends masked and greased | Local fabricator with a lathe | 110.00 | make | 21.3 kg each (model); SDG-DWG-103
4 Spur gear 84 teeth | 2 | Module 4, 84 teeth, 30 mm face, C45, webbed blank, bored 40 mm with a 12 mm keyway and set screw | Gear cutting shop or power transmission stockist (India) | 95.00 | buy | Indicative price; bought cut and bored; 10.2 kg (model)
5 Crank shaft and pinion | 2 | 25 mm C45 bright bar 690 mm with two cross-pin holes and a keyway; pinion module 4, 14 teeth, 35 mm face, bored 25 mm and keyed | Gear shop (pinion); local machinist (shaft) | 40.00 | make | SDG-DWG-104; pinion bought and keyed on
6 Flange bearing 40 mm | 4 | Four-bolt flange bearing, 40 mm bore (UCF208 size), stainless steel insert in a thermoplastic housing, stainless set screws, sealed | Bearing distributor | 38.00 | buy | Indicative price; two per capstan on the drum shaft; corrosion-resistant type chosen for brine (SDG-DDR-001)
6b Flange bearing 25 mm | 4 | Four-bolt flange bearing, 25 mm bore (UCF205 size), stainless steel insert in a thermoplastic housing | Bearing distributor | 28.00 | buy | Indicative price; two per capstan on the crank shaft
7 Ratchet wheel and pawl | 2 | Ratchet wheel 200 mm, 20 teeth, 20 mm thick, C45, flame or laser cut, bored 40 mm and keyed; pawl 16 mm C45 plate, hardened tip; M24 pivot bolt with nyloc nut; stainless return spring | Local fabricator with laser or flame cutting | 30.00 | make | SDG-DWG-105
8 Brake band and lever | 2 | Band 40 x 3 mm steel strip with 5 mm woven brake lining riveted on, wrapped about 245 deg round the brake rim; two 10 mm end links; lever 450 mm of 25 mm round bar with an inner arm and 20 mm pivot shaft; handle grip | Local fabricator; lining from a vehicle brake parts shop | 25.00 | make | SDG-DWG-106; differential band brake for paying out under control
9 Crank handle | 4 | Hub 50 mm OD x 40 mm bored 25 mm with a cross-pin and R-clip; arm 40 x 10 mm flat bar, 330 mm centres; 32 mm grip turning on a 16 mm pin; galvanised | Local fabricator | 10.00 | make | Two per capstan; removable (taken off before paying out under load); SDG-DWG-104
10 Gear guard | 2 | 2 mm steel sheet cup round the gear and pinion, 50 mm deep, on three 14 mm spacers with M8 bolts; painted bright yellow | Local fabricator | 20.00 | make | SDG-DWG-107
11 Ground anchor | 4 | Helical ground anchor, 20 mm rod 1.0 m long, one 150 mm helix, forged eye, hot-dip galvanised | Agricultural fencing or tent-anchor supplier | 15.00 | buy | Indicative price; two per capstan; holding to be proved on site (CalRig proof load)
11b Anchor chain and turnbuckle set | 4 | 8 mm grade 30 galvanised chain 1.4 m, M16 hook-and-eye galvanised turnbuckle, two 10 mm bow shackles | Hardware and rigging shop | 22.00 | buy | Indicative price; two per capstan
12 Bund roller saddle | 2 | Two 6 mm steel side plates 300 x 140 mm on 80 x 6 mm foot plates, two 20 mm tie bars, galvanised; UHMW-PE roller 100 mm x 200 mm with 160 mm flanges; 25 mm stainless 316 axle 260 mm with R-clips | Local fabricator; UHMW-PE from a plastics stockist | 45.00 | make | SDG-DWG-108; 9.9 kg each (model)
13 Rake beam | 1 | Pultruded FRP (glass and polyester or vinylester) square tube 100 x 100 x 6 mm, 3,000 mm, drilled | FRP profile maker (India) | 110.00 | buy | Indicative price; 12.8 kg; SDG-DWG-109
14 Rake blade | 1 | UHMW-PE sheet 15 mm, 3,000 x 300 mm, drilled and countersunk for the bolts | Plastics stockist | 190.00 | buy | Indicative price; 12.7 kg; SDG-DWG-110
15 Skid and hanger | 3 | UHMW-PE skid 60 x 20 x 450 mm with a chamfered nose, counterbored; stainless 316 hanger, 6 mm plate bent to an L, two 11 x 24 mm slots | Plastics stockist; local fabricator | 22.00 | make | SDG-DWG-111; slots set the blade 5 to 25 mm above the floor
16 End cap with eye plate | 2 | Stainless 316 sheet 6 mm folded round the beam end (top, bottom, rear and end), 12 mm eye plate welded on with two 18 mm eyes | Local stainless fabricator | 45.00 | make | SDG-DWG-112
17 Bridle and swivel set | 2 | Two 12 mm polyester legs about 2.5 m with spliced thimble eyes; galvanised swivel eye-to-eye 1 t; three 10 mm bow shackles | Rope and rigging shop | 35.00 | buy | Indicative price; one bridle each side of the rake
18 Pull rope | 2 | 12 mm polyester double braid, 45 m, minimum breaking strength at least 25 kN, eye splice with thimble at the rake end, whipped plain end at the drum | Rope maker or chandler | 95.00 | buy | Indicative price (about USD 2 per metre); low stretch chosen to limit snap-back
19 Fastener set | 1 | Stainless 316: 30 M10 bolts with nyloc nuts and washers, 30 stainless crush sleeves 16 x 2 mm, 4 M12 bolts; galvanised M10 and M12 bolts for the capstan frames and bearings; keys and set screws | Fastener stockist | 75.00 | buy | Indicative price
20 Rope damper | 2 | Canvas bag about 5 kg (filled with sand or salt), with a snap hook that rides on the rope | Local tailor or chandler | 8.00 | buy | Hung on the loaded rope mid-span to absorb snap-back
21 Maintenance kit | 1 | 20 L freshwater can and brush for rinsing, marine grease and gun, spare pawl and spring, spare brake lining, spare shackles and R-clips, spanners | Hardware shop | 60.00 | buy | Indicative price; the rinse after each day of work is part of the corrosion plan
22 Ballast bag and straps | 2 | Woven polypropylene bag about 550 x 300 x 120 mm filled with about 24 kg of salt on site, two 25 mm ratchet straps | Local market | 6.00 | buy | Keeps the blade down as the rope steepens near the bund (SDG-CAL-001 [D3] and [D4])
23 Fabrication labour and hot-dip galvanising | 1 | Cutting, welding, drilling and assembly of two capstans, two rollers and the rake; galvanising of steel parts not covered in the item prices | Local fabricator | 450.00 | make | Estimate for a first prototype in a town workshop near the Rann

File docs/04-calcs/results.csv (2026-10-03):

label | value | unit | description
A1 | 0.193 | m3 | heap held in front of the blade when full
A2 | 231.360 | kg | salt in a full heap
A3 | 1588.749 | N | force to slide the full heap over the bed
A4 | 900.000 | N | allowance to loosen and lift the harvest layer
A5 | 40.436 | kg | rake mass without ballast (model)
A5b | 47.520 | kg | two ballast bags filled with salt on site (model)
A6 | 258.854 | N | skid friction
A7 | 2747.603 | N | design drag on the rake with a full heap
A8 | 3003.676 | N | rope pull at the drum
B1 | 6.000 |  | gear ratio (84 to 14 teeth)
B2 | 110.934 | mm | rope radius on the drum at the end of a 30 m pass (layer 3)
B3 | 89.439 | N | force on each crank handle at the design drag
B4 | 4030.037 | N | rope pull with two people at 120 N, layer 3
B5 | 3684.850 | N | rope pull with two people at 120 N, layer 4 (full drum)
B6 | 0.053 | m/s | rope speed at 30 crank turns a minute
B7 | 84.037 | W | work rate of each cranker
B8 | 58.465 | m | rope the drum holds in four layers
B9 | 37.674 | mm | flange freeboard above the fourth layer
C1 | 147.347 | MPa | drum shaft, 40 mm, combined stress at 6 kN
C1b | 2.307 |  | drum shaft margin to yield at 6 kN
C2 | 161.465 | MPa | crank shaft, 25 mm, at the overhung pinion, 6 kN
C2b | 2.106 |  | crank shaft margin to yield at 6 kN
C3 | 138.560 | MPa | pinion tooth bending (Lewis) at 6 kN
C3b | 2.454 |  | pinion tooth margin to yield at 6 kN
C4 | 7827.484 | N | pawl tip force at 6 kN
C5 | 58.804 | MPa | pawl boss bending (40 mm boss welded to the cheek) at 6 kN
C5b | 4.677 |  | pawl boss margin to yield (S275 tube)
C6 | 247.349 | deg | brake band wrap
C7 | 92.442 | N | hand force on the brake lever to hold the rated pull (50 mm inner arm)
C8 | 7.650 |  | rope working-load factor at the rated pull, after splices
C9 | 3259.897 | N | each chain at 6 kN (two chains)
C9b | 2.393 |  | chain working load limit over the 6 kN chain force
C10 | 7952.156 | N | holding of one 150 mm helix in firm clay (estimate)
C10b | 2.439 |  | anchor holding over the 6 kN chain force
C11 | 102.067 | kg | capstan mass without anchors (model)
C12 | 1.553 |  | capstan resistance to tipping over the rated pull
C13 | 27.977 | MPa | rake beam bending at 6 kN
C13b | 7.149 |  | rake beam margin to FRP flexural strength
C14 | 11.404 | mm | rake beam bow at the rated load
D1 | 10.652 | kPa | skid pressure on the floor with ballast
D2 | 10.000 | mm | blade edge above the floor, set by the skids
D3 | 5.909 | m | blade distance from the bund toe where the rope starts to lift the rake, without ballast
D4 | 3.297 | m | blade distance from the bund toe where the rope starts to lift the rake, with ballast
D5 | 9.498 | min | winding a 30 m pass
D6 | 5.699 | min | winding the empty rake back
D7 | 23.197 | min | one strip: pull, return and move 3 m
D8 | 598.435 | kg/h | salt gathered to the windrow per hour (one full heap per strip)
D9 | 149.609 | kg per worker-hour | gathering rate per worker, crew of four
D10 | 19.000 | min | set-up time per crew (two crews work at once)
E1 | 23.760 | kg | heaviest single part (Ballast bags (2))
E2 | 2803.000 | USD | estimated parts cost of the full set (bom/bom.csv)
E3 | -1197.000 | USD | over (+) or under (-) the value-engineering target of USD 4,000

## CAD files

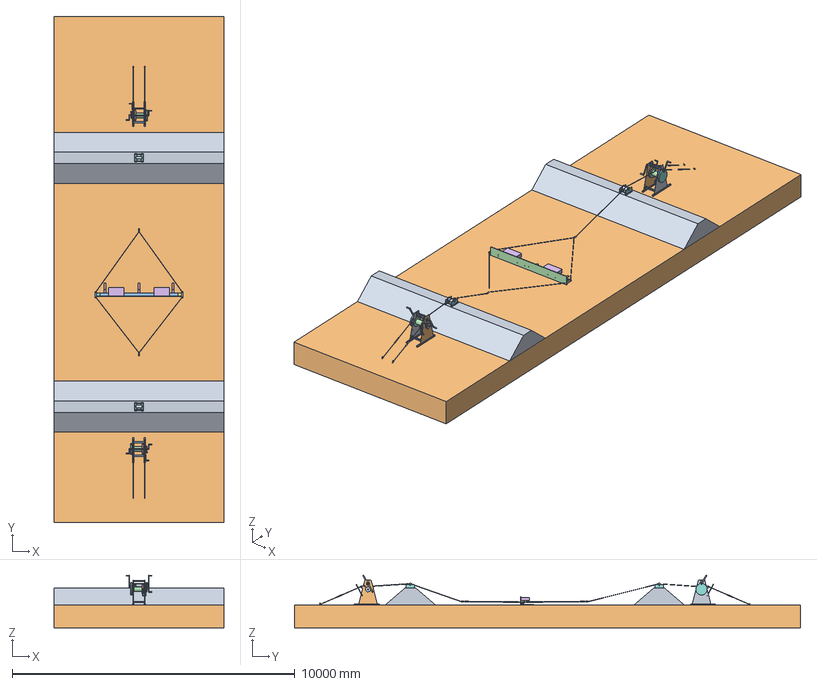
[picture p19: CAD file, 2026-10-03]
cad/step/saltdrag-assembly.step
6000.0 x 17900.0 x 1861.7 mm

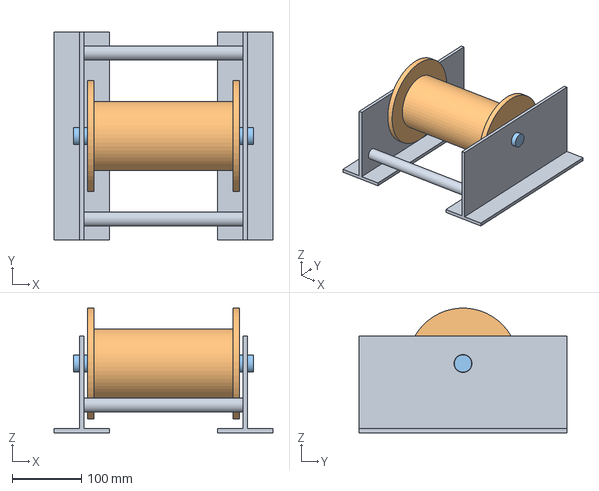
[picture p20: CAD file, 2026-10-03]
cad/step/saltdrag-roller.step
316.0 x 300.0 x 179.8 mm

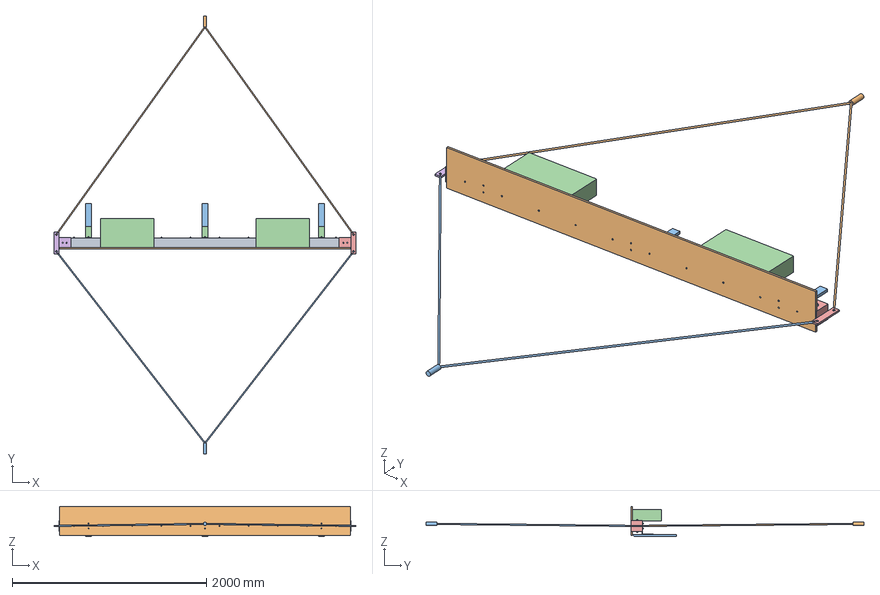
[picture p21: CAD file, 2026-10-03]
cad/step/saltdrag-rake.step
3112.0 x 4510.0 x 310.0 mm

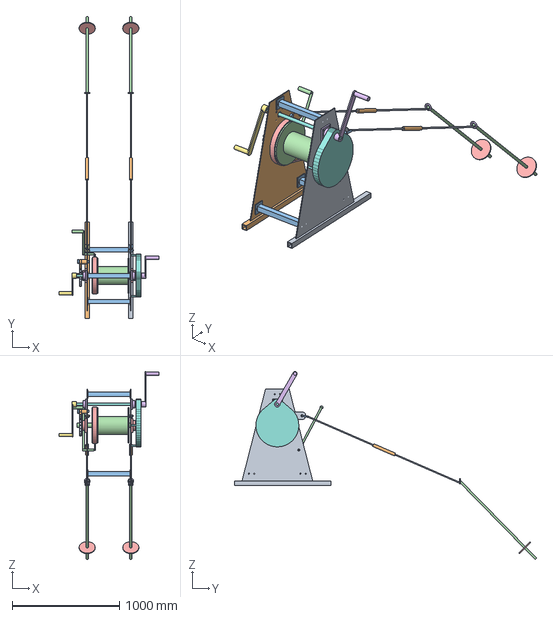
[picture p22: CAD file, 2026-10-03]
cad/step/saltdrag-capstan.step
930.0 x 2814.2 x 1750.9 mm

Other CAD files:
cad/stl/saltdrag-capstan.stl
cad/stl/saltdrag-rake.stl
cad/stl/saltdrag-roller.stl

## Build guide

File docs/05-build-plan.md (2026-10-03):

---
doc_id: SDG-BLD-001
title: SaltDrag prototype build plan
project: SaltDrag
doc_type: Build plan
version: "0.1"
status: Draft
date: '2026-10-03'
author: Amish Chadha
license: CERN-OHL-S-2.0
revisions:
- version: "0.1"
  date: '2026-10-03'
  author: Amish Chadha
  change: First build plan; design made constructable (SDG-DDR-002)
---

# SaltDrag prototype build plan

**Plan, not yet built.** How to build the first proof-of-concept prototype, component by component. Building and testing to it is TRL 4 work. Decisions still to be made are kept in the design decisions register ([docs/06-design-decisions.md](06-design-decisions.md)), not here.

## 1. What you are building

Figure 1. Every component, pulled apart and numbered in build order

*Figure 1. Every component pulled apart and numbered in build order. One capstan, one bund roller and one rope are shown; the set has two of each.*

The prototype is one SaltDrag set: two identical hand capstans, two bund rollers, two 45 m pull ropes and one 3 m rake. Each capstan is a pair of galvanised steel side frames bolted together by three cross tubes, carrying a welded drum, a gear pair, a ratchet and pawl, a band brake, a gear guard and two crank handles, and held to the ground by two chains and screw-in anchors. The rake is a green FRP box beam with a white plastic blade bolted to its front, three plastic skids, stainless end caps for the bridles and two salt-filled ballast bags. Figure 1 shows the 20 kinds of component in the order you make or fit them. Thirteen are made in a town workshop: the side frames, cross tubes, drum, crank shaft, crank handles, ratchet and pawl, brake, gear guard, roller saddle, and the drilled beam, blade, skids and end caps. The gears, bearings, anchors, chains, ropes, bridles, fasteners and bags are bought. The work is cutting, drilling and welding steel plate and tube, some lathe work on the drum, galvanising, and drilling plastic and FRP. The parts cost about USD 2,803 for the whole set, from the bill of materials.

> **Safety:** This is rope and lifting-class equipment. A loaded rope can whip back if it breaks or slips, cranks and gears can trap hands, and a ground anchor can pull out. Do not load any part until section 6 says so. Welding and galvanised steel give off fumes: weld only bare steel and galvanise afterwards, in a ventilated space. Drilling FRP makes glass dust: wear a dust mask and gloves. Parts weigh up to 24 kg: lift in pairs.

## 2. What changed to make it buildable

The concept showed what SaltDrag does; it did not say how any part is made or fixed. Each change below keeps what the set does, and all of them are recorded in decision record SDG-DDR-002.

*Table 1. Changes from the concept.*

| Component | The concept had | The buildable design has | Why |
| --- | --- | --- | --- |
| Capstan frame | A portable geared drum | Two side frames bolted together by three cross tubes (Figures 2 and 4) | Each piece weighs under 21 kg; the drum fits between the cheeks |
| Capstan position | Staked on the bund | On dry ground behind the bund, with a roller saddle on the crest (Steps 16 and 17) | The crest is too narrow to crank on; the roller keeps the rope off the bund |
| Drum | A drum | Welded pipe barrel and flanges, brake rim, shaft welded through (Figure 5) | Holds 58 m of rope; carries the brake |
| Ratchet and pawl | A pawl | The pawl on a 40 mm boss welded to the cheek (Figure 12) | A plain pin would bend at twice the rated pull |
| Brake | A brake | A lined band round the brake rim, worked by a lever through the cheek (Figure 14) | Holds the rated pull with about 92 N on the lever |
| Anchoring | Screw or plate anchors | An ear on each cheek at rope height, shackle, chain and turnbuckle to a screw-in anchor (Figure 3) | The capstan cannot tip |
| Rake | Bolted sections | One 3 m FRP beam, blade bolted on with crush sleeves, skids on slotted hangers, end caps with eye plates (Figures 18 to 24) | Light, rust-free, and the bridles pull on parts made for the load |
| Ballast | None | Two salt-filled bags on the beam (Step 18) | Keeps the blade down as the rope steepens near the bund |
| Windrow board | A board at the bund edge | Removed | The rake lifts about 3.3 m from the bund toe, so the windrow forms there |

## 3. Making the components

Make and check each component before the assembly step that needs it. Sizes are in millimetres. "Left" and "right" are as seen standing in the pan looking at the capstan (the ratchet and brake are on the left, the gears on the right). "Ahead" is toward the pan, "behind" is away from it. Heights are from the ground under the capstan. Workshop tolerance is 1 mm on steelwork and 0.5 mm on holes and shafts unless a step says otherwise; drawings carry no tolerances before TRL 4.

### 3.1 Side frames (make 4)

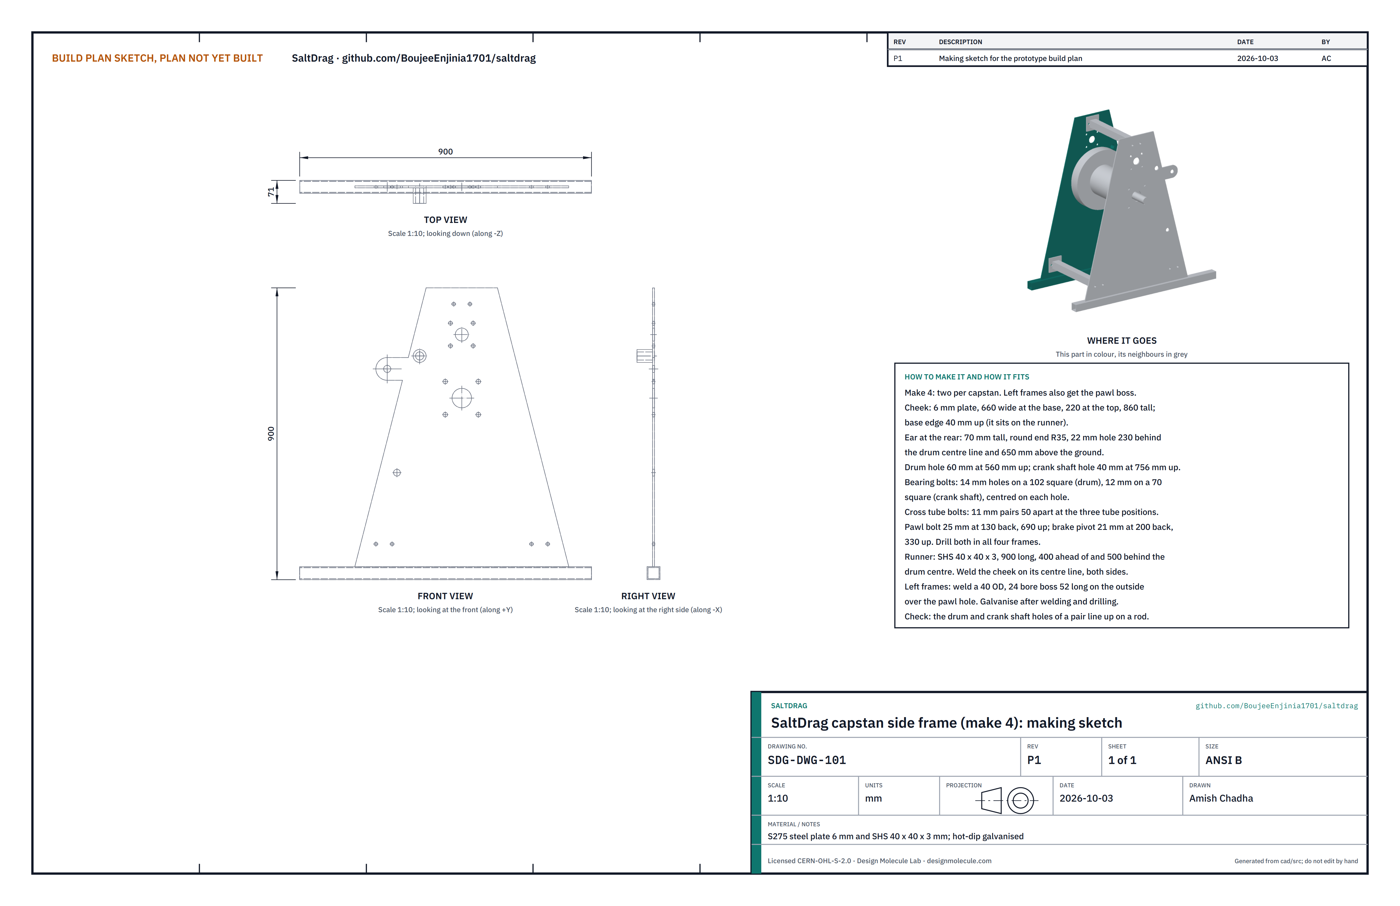
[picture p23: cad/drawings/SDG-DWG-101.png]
Figure 2. Making sketch of a side frame


*Figure 2. Side frame making sketch (SDG-DWG-101); a left frame, with the pawl boss, is shown.*

**What it is and what it is made from.** Each capstan has a left and a right side frame: a tall steel cheek plate welded on a box-section runner that sits on the ground like a sledge. S275 steel plate 6 mm, and square hollow section 40 x 40 x 3 mm, 900 mm long. The two left frames also carry a short round boss for the pawl.

**How to make it.**

1. Cut the cheek from 6 mm plate: a trapezoid 660 wide at the base, 220 wide at the top and 860 tall, with the ear at the rear (a tab 70 tall ending in a 35 mm radius, centred 230 behind the drum centre line and 650 above the ground).
2. Mark the drum centre line square to the base. All hole positions are measured ahead or behind this line and up from the ground (the base edge of the cheek is 40 up).
3. Drill the 60 mm drum hole at 560 up and the 40 mm crank shaft hole at 756 up, both on the centre line.
4. Drill the bearing bolt holes: four 14 mm holes on a 102 mm square round the drum hole, four 12 mm holes on a 70 mm square round the crank shaft hole.
5. Drill the cross tube bolt holes: pairs of 11 mm holes 50 apart, at 240 ahead and 110 up, 240 behind and 110 up, and on the centre line at 850 up.
6. Drill the 22 mm hole in the ear, the 25 mm pawl bolt hole at 130 behind and 690 up, and the 21 mm brake pivot hole at 200 behind and 330 up. Drill these in all four frames, so any frame can be used either side.
7. Drill three 9 mm holes for the gear guard spacers, 190 from the drum hole centre: ahead, behind and below it (right frames only).
8. Cut the runner 900 long; it extends 400 ahead of and 500 behind the drum centre line. Weld the cheek on the runner's centre line, fillet welds both sides.
9. Left frames: weld a 40 mm OD, 24 mm bore tube 52 long on the outside face over the pawl hole, square to the plate.
10. Deburr, then hot-dip galvanise. Run a drill through the bolt holes afterwards.

**How it fits the parts next to it.** The cross tubes' end plates sit flat on the inner face of the cheek, two M10 bolts each (Figure 3a). The bearings bolt to the outer face. The ear takes a 10 mm bow shackle and the anchor chain, which runs back and down to the ground anchor (Figure 3).

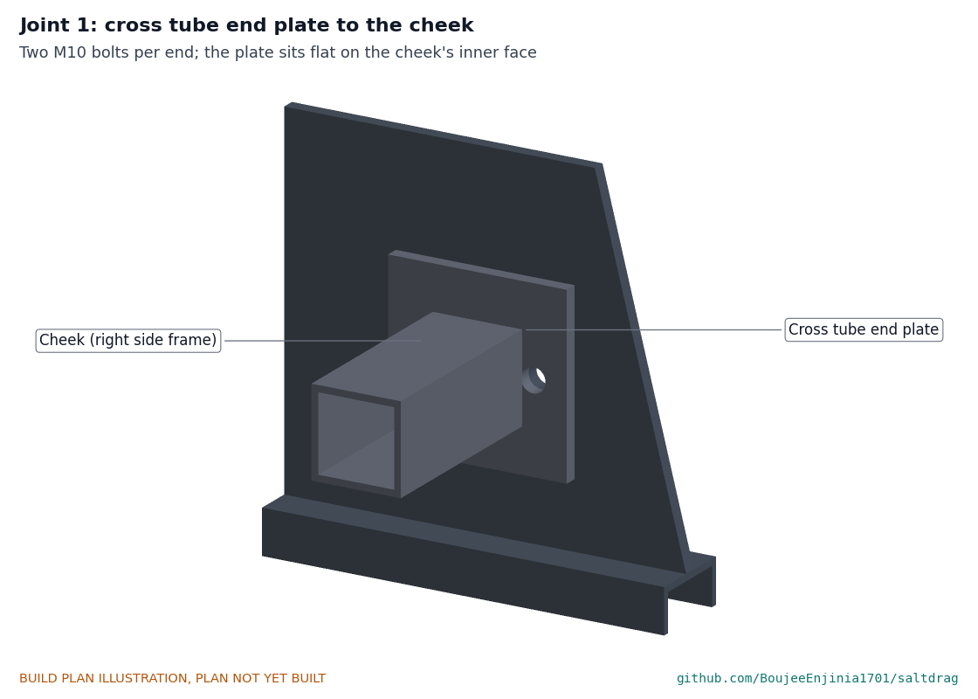
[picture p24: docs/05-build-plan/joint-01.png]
Figure 3a. Joint 1: cross tube end plate to the cheek


*Figure 3a. Cross tube end plate on the inner face of the cheek.*

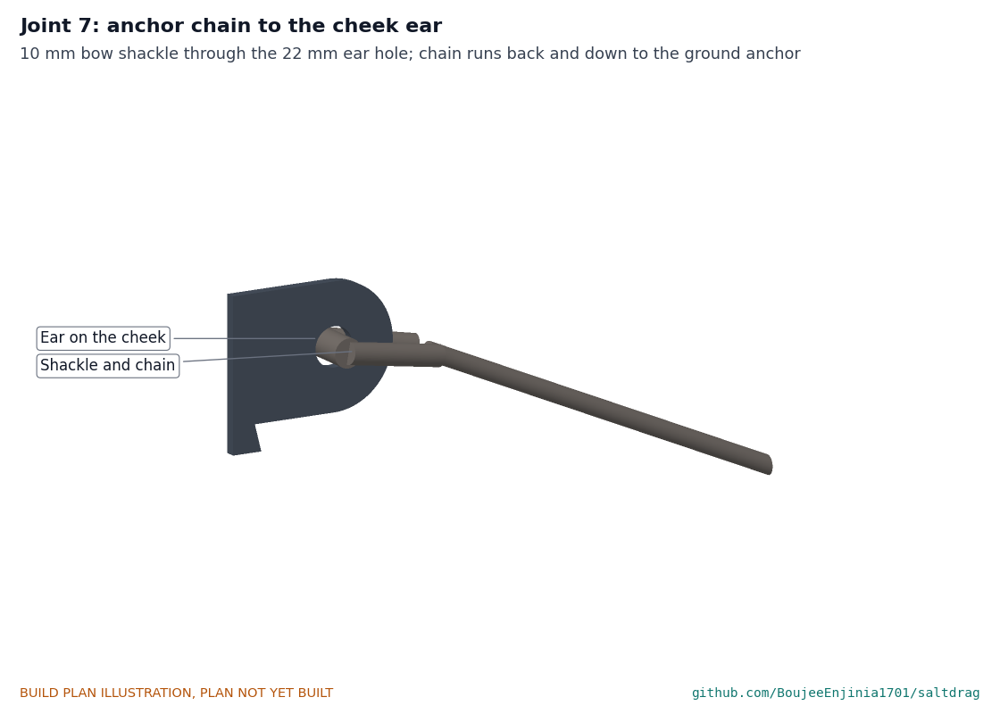
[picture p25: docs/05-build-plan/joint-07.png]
Figure 3. Joint 7: anchor chain to the cheek ear


*Figure 3. Shackle through the ear, chain running back to the anchor.*

**Check before moving on.** Stand a left and a right frame up 406 mm apart (centres) and pass a straight 40 mm rod through both drum holes and a 25 mm rod through both crank shaft holes: both rods must pass without forcing.

### 3.2 Cross tubes (make 6)

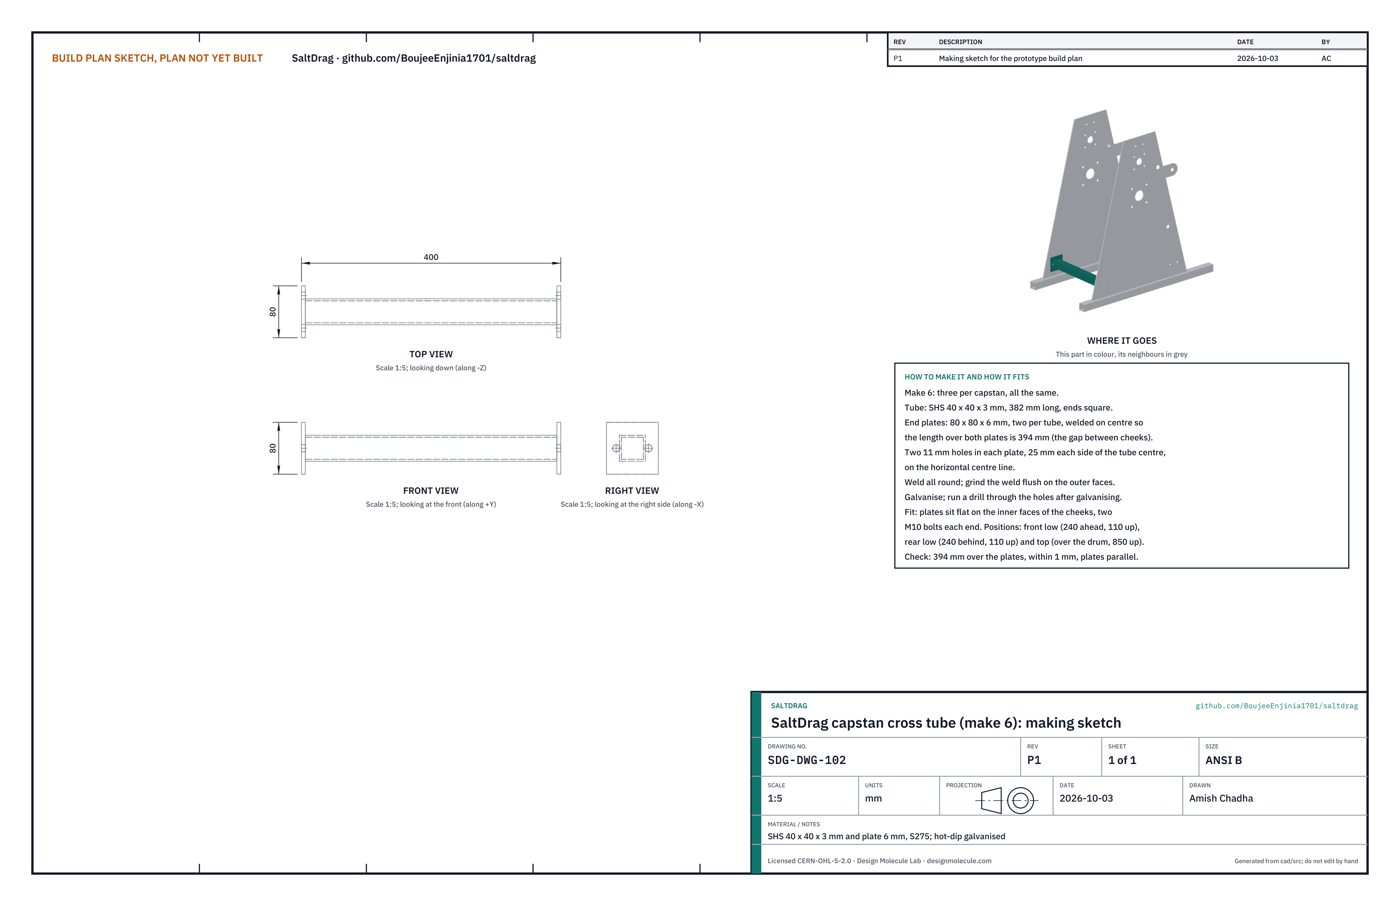
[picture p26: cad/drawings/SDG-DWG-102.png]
Figure 4. Making sketch of a cross tube


*Figure 4. Cross tube making sketch (SDG-DWG-102).*

**What it is and what it is made from.** Three per capstan, all the same: square hollow section 40 x 40 x 3 mm with an 80 x 80 x 6 mm end plate welded on each end.

**How to make it.**

1. Cut the tube 382 long, ends square.
2. Cut two 80 x 80 mm plates and drill two 11 mm holes in each, 25 each side of the centre.
3. Weld a plate on each end, centred, so the length over both plates is 394. Weld all round and grind flush on the outer faces.
4. Galvanise, then run a drill through the holes.

**How it fits the parts next to it.** The plates sit flat on the inner faces of the two cheeks (Figure 3a): front low (240 ahead, 110 up), rear low (240 behind, 110 up) and top (on the centre line, 850 up). Two M10 bolts each end.

**Check before moving on.** 394 over the plates, within 1 mm; the plates are parallel.

### 3.3 Drum (make 2)

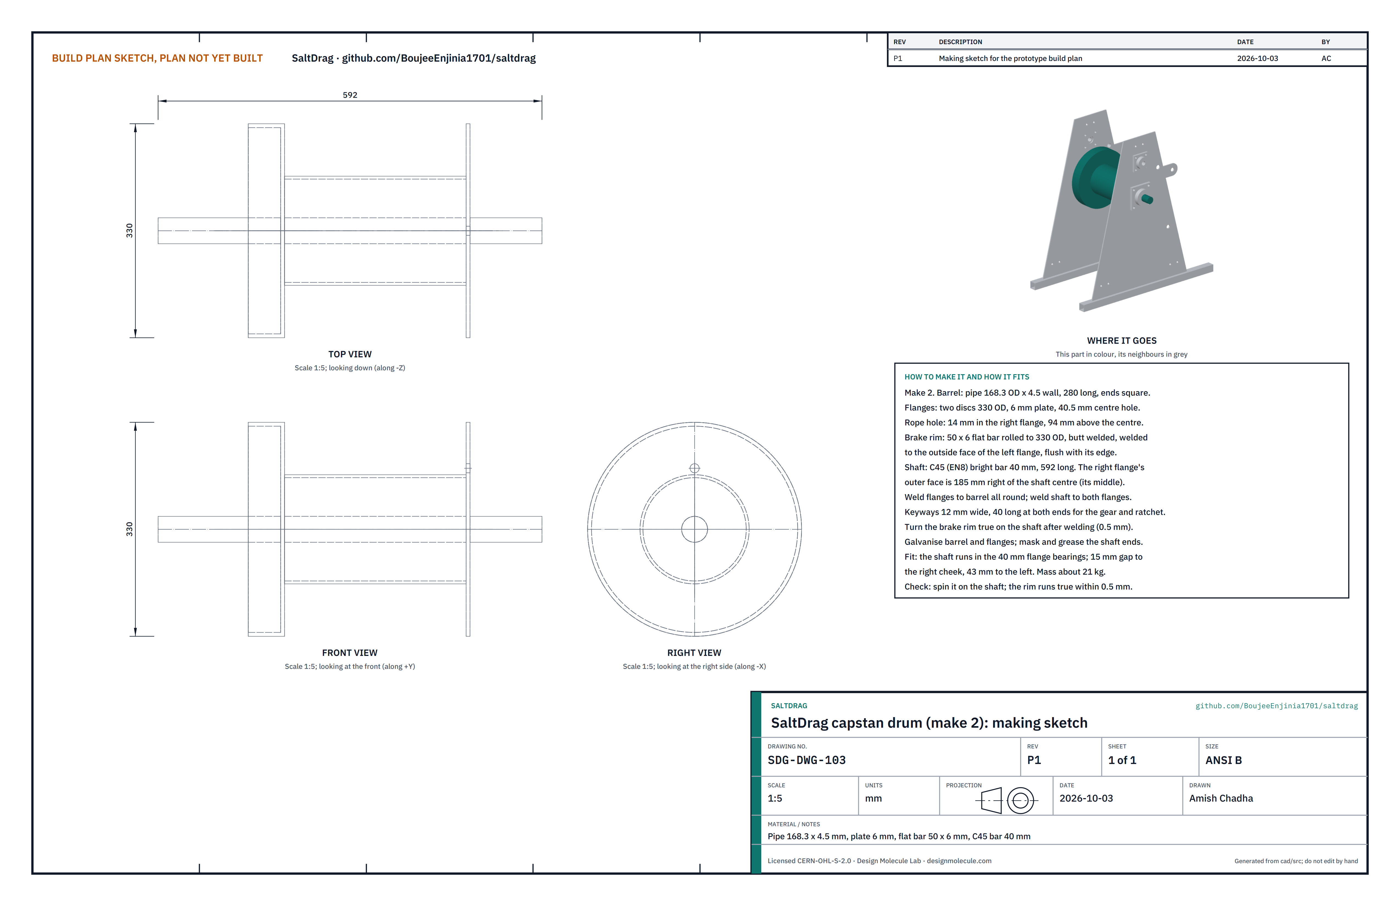
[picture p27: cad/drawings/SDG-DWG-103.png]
Figure 5. Making sketch of the drum


*Figure 5. Drum making sketch (SDG-DWG-103).*

**What it is and what it is made from.** The drum stores the pull rope. A barrel of steel pipe 168.3 x 4.5 mm, 280 long; two flanges of 6 mm plate, 330 diameter; a brake rim of 50 x 6 mm flat bar on the left flange; and a 40 mm C45 (EN8) bright steel shaft, 592 long, welded right through.

**How to make it.**

1. Cut the barrel 280 long, ends square. Cut two 330 mm discs from 6 mm plate with a 40.5 mm centre hole.
2. Drill a 14 mm rope hole in the right flange, 94 above the centre (just outside the barrel).
3. Roll the 50 x 6 flat bar to a ring 330 outside diameter, butt weld it, and weld it to the outside face of the left flange, flush with its edge.
4. Slide both flanges and the barrel onto the shaft. The right flange's outer face is 185 right of the shaft's middle; the left flange's outer face is 107 left of it. Tack, check square, then weld the flanges to the barrel all round and to the shaft.
5. Cut a 12 mm keyway 40 long at each shaft end, for the gear (right) and the ratchet wheel (left).
6. Turn the brake rim true on the shaft in a lathe (within 0.5 mm).
7. Galvanise the barrel and flanges with the shaft ends masked; grease the shaft ends.

**How it fits the parts next to it.** The shaft runs in a 40 mm flange bearing on each cheek; the right flange stands 15 clear of the right cheek and the brake rim 43 clear of the left one. The gear is keyed on the right shaft end, 10 clear of the bearing (Figure 6).

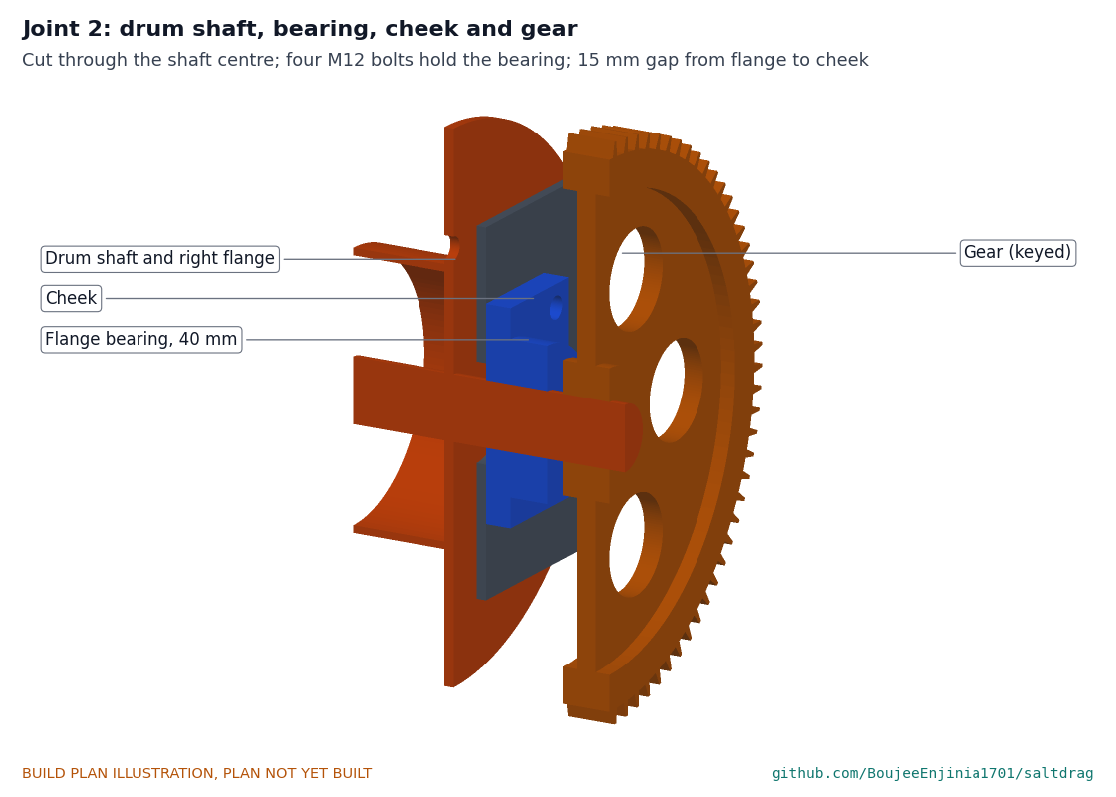
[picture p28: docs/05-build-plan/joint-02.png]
Figure 6. Joint 2: drum shaft, bearing, cheek and gear


*Figure 6. Cut through the shaft centre: shaft, bearing, cheek and gear.*

**Check before moving on.** Spin the drum on its shaft between centres: the brake rim runs true within 0.5 mm and the flanges within 2 mm. It weighs about 21 kg.

### 3.4 Crank shaft and pinion (make 2)

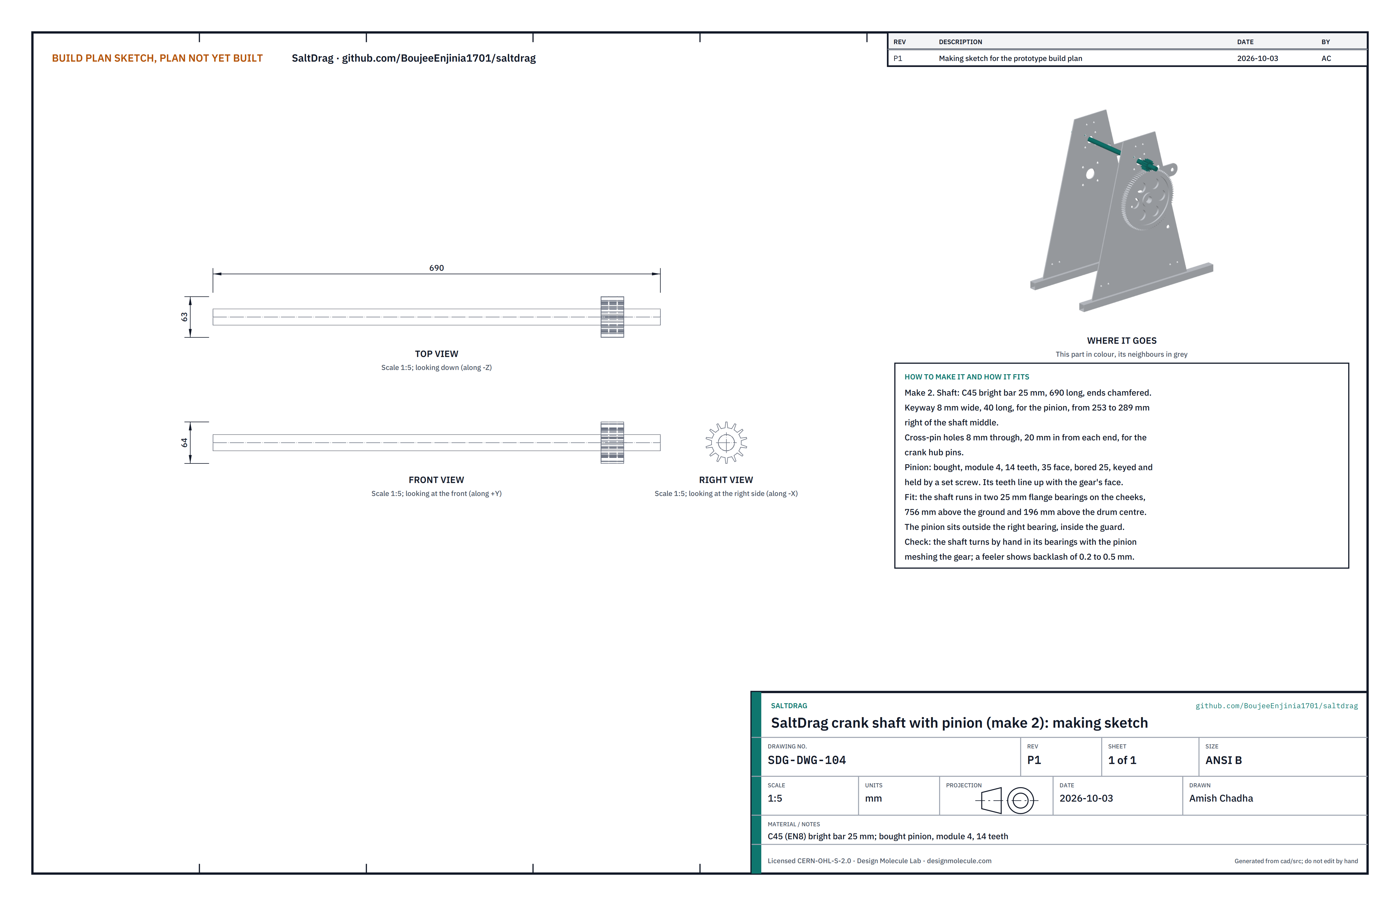
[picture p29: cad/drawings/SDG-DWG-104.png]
Figure 7. Making sketch of the crank shaft


*Figure 7. Crank shaft with pinion making sketch (SDG-DWG-104).*

**What it is and what it is made from.** C45 bright steel bar 25 mm, 690 long, with a bought pinion: module 4, 14 teeth, 35 mm face, bored 25 mm.

**How to make it.**

1. Cut the bar 690 long and chamfer the ends.
2. Cut an 8 mm keyway 40 long, from 253 to 289 right of the bar's middle.
3. Drill 8 mm cross holes 20 in from each end, for the crank pins.
4. Key the pinion on and lock its set screw once it is in place (Step 6).

**How it fits the parts next to it.** The shaft runs in two 25 mm flange bearings, 756 up and 196 above the drum centre. The pinion sits outside the right bearing and meshes the gear inside the guard (Figure 8).

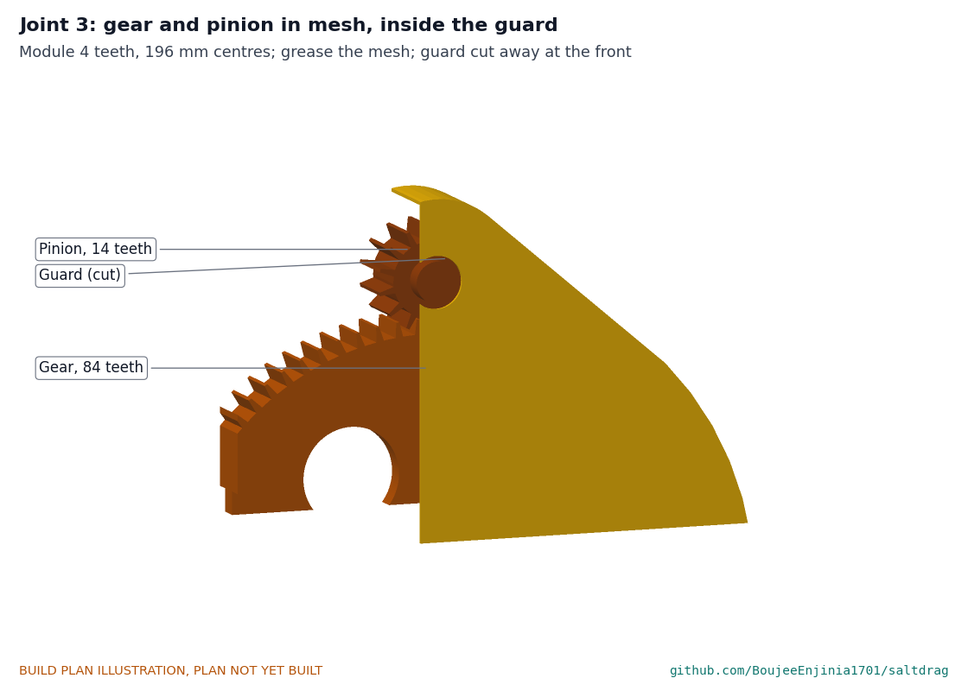
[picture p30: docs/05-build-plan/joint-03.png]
Figure 8. Joint 3: gear and pinion in mesh


*Figure 8. Gear and pinion in mesh, guard cut away at the front.*

**Check before moving on.** The shaft turns by hand in its bearings; with the pinion in mesh, a feeler gauge shows 0.2 to 0.5 mm of backlash.

### 3.5 Crank handles (make 4)

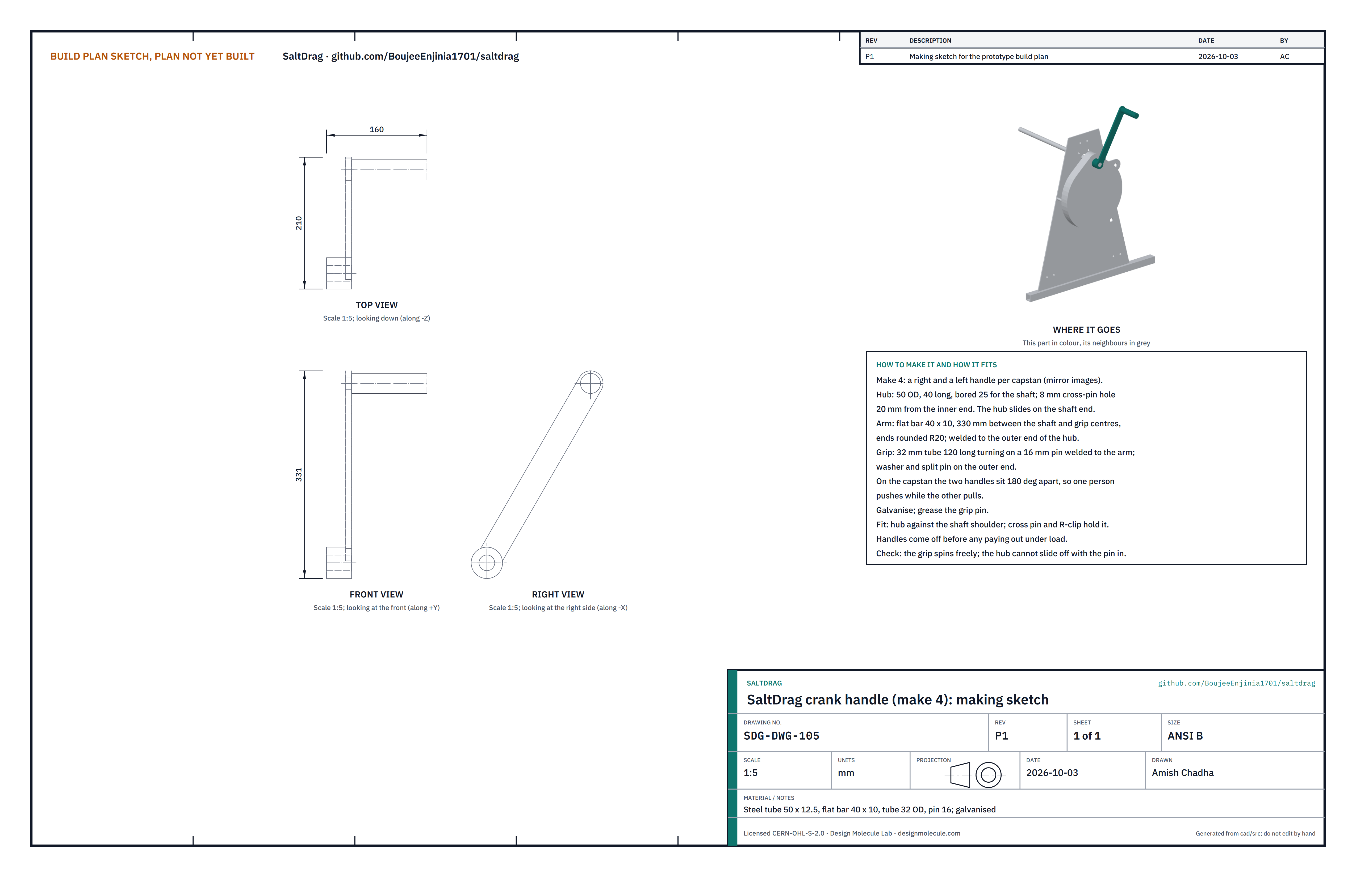
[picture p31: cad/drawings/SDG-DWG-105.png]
Figure 9. Making sketch of a crank handle


*Figure 9. Crank handle making sketch (SDG-DWG-105).*

**What it is and what it is made from.** A right and a left handle per capstan, mirror images: a hub of thick-wall tube 50 x 12.5 mm, an arm of 40 x 10 mm flat bar and a 32 mm grip turning on a 16 mm pin. Galvanised.

**How to make it.**

1. Cut the hub 40 long and bore it to 25 mm. Drill an 8 mm cross hole 20 from its inner end.
2. Cut the arm and round both ends to 20 radius; the shaft and grip centres are 330 apart.
3. Weld the arm to the outer end of the hub, square to it.
4. Weld the 16 mm pin to the arm's free end, slide on the 120 mm grip tube and a washer, and fit a split pin.
5. Galvanise; grease the grip pin.

**How it fits the parts next to it.** The hub slides onto the crank shaft end and is held by an 8 mm cross pin and R-clip through hub and shaft (Figure 10). The two handles on a capstan sit 180 degrees apart.

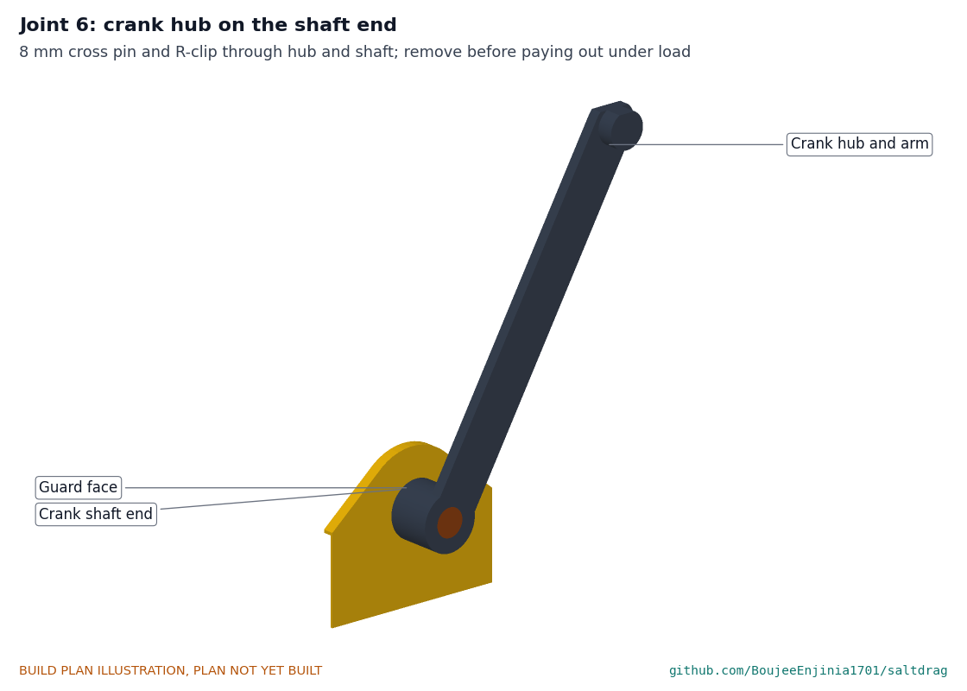
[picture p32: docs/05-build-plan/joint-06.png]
Figure 10. Joint 6: crank hub on the shaft end


*Figure 10. Crank hub on the shaft end, outside the guard.*

**Check before moving on.** The grip spins freely; with the pin in, the hub cannot slide off.

### 3.6 Ratchet wheel and pawl (make 2 sets)

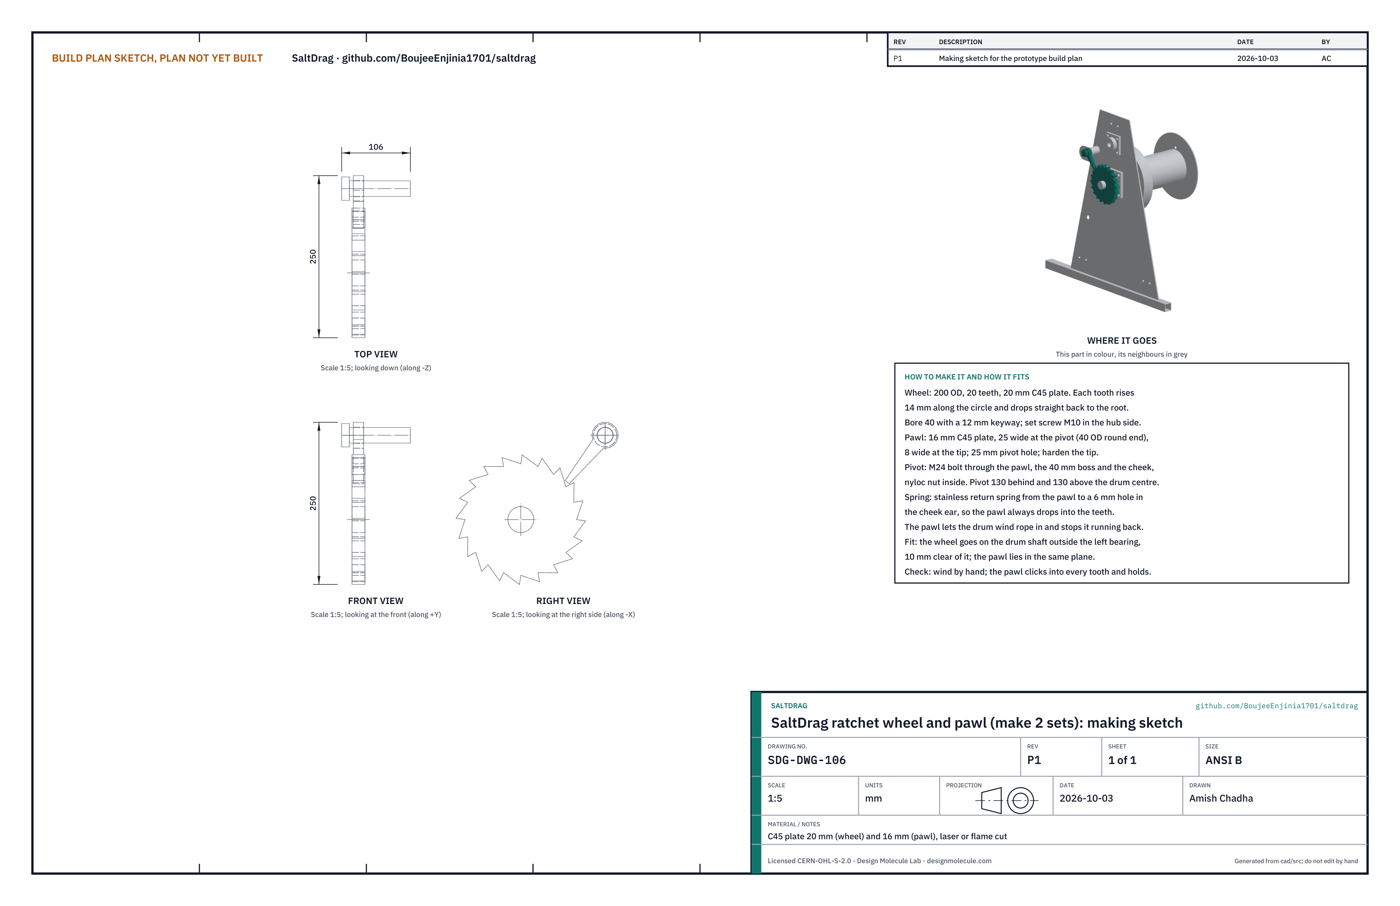
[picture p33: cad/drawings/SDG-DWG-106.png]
Figure 11. Making sketch of the ratchet wheel and pawl


*Figure 11. Ratchet wheel and pawl making sketch (SDG-DWG-106).*

**What it is and what it is made from.** C45 plate, laser or flame cut: the wheel from 20 mm, the pawl from 16 mm. An M24 bolt is the pawl's pivot; a stainless spring keeps it in the teeth.

**How to make it.**

1. Cut the wheel 200 diameter with 20 teeth: each tooth rises 14 mm along the circle and drops straight back to the root.
2. Bore it 40 mm with a 12 mm keyway; drill and tap a set screw hole.
3. Cut the pawl: a 40 mm round end with a 25 mm hole, tapering to an 8 mm tip; harden the tip.
4. Drill a 6 mm hole near the pawl's tip end for the spring.

**How it fits the parts next to it.** The wheel is keyed on the left drum shaft end, 10 clear of the bearing. The pawl turns on the M24 bolt through its hole, the boss and the cheek, with a nyloc nut inside; its tip drops onto the face of a tooth (Figure 12). The spring runs from the pawl to a 6 mm hole in the ear.

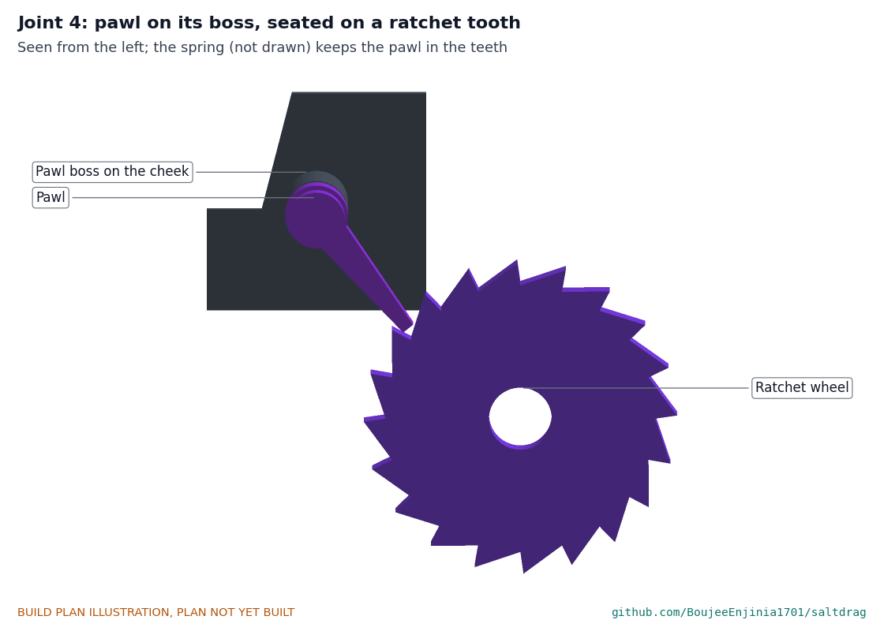
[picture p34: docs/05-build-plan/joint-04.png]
Figure 12. Joint 4: pawl seated on a ratchet tooth


*Figure 12. Pawl on its boss, seated against a tooth face (spring not drawn).*

**Check before moving on.** Turn the drum to wind rope in: the pawl clicks into every tooth. Try to turn it back: the pawl holds.

### 3.7 Brake band and lever (make 2)

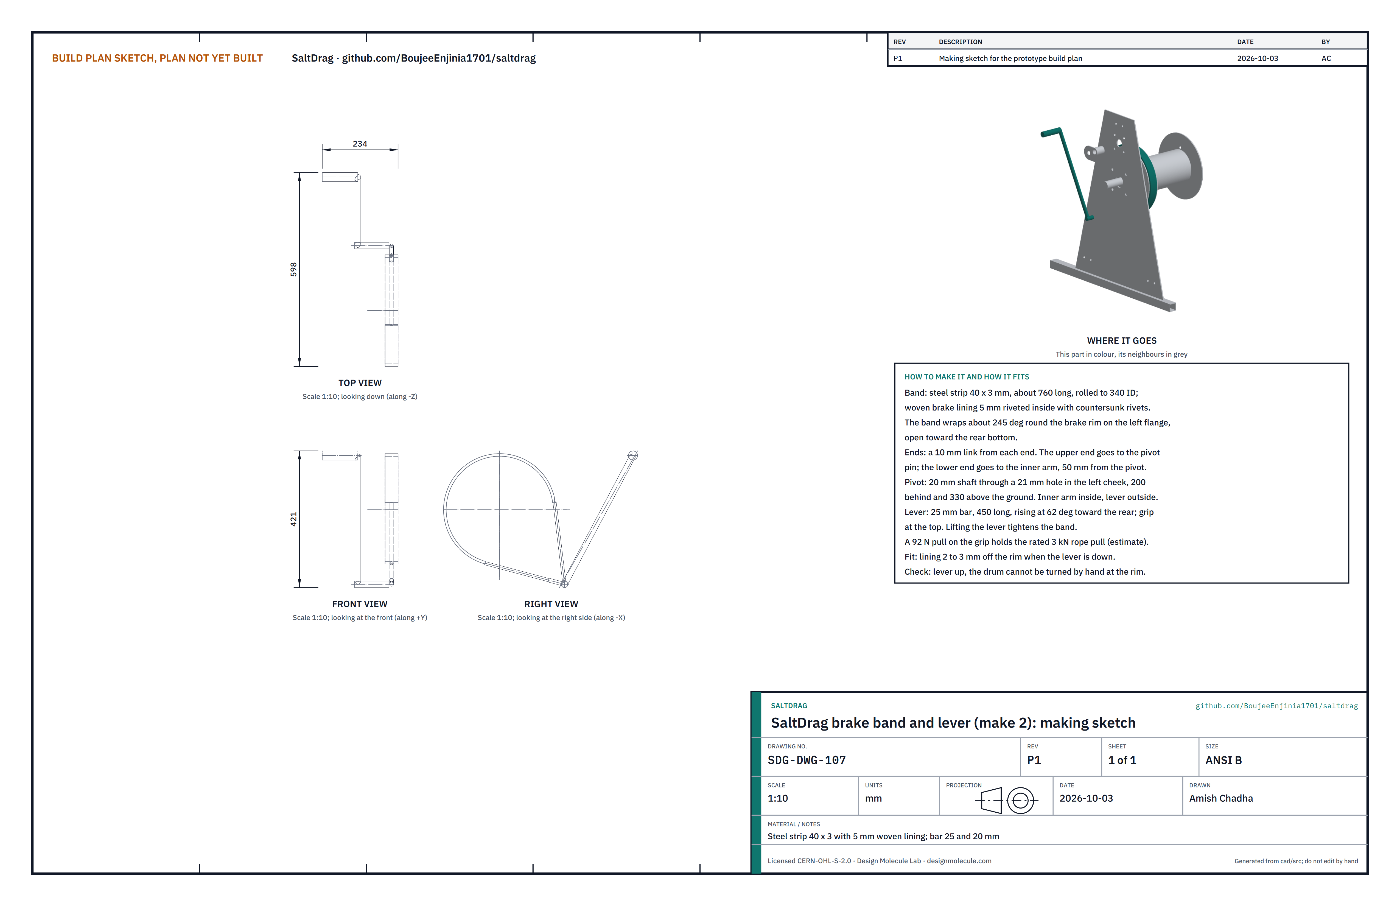
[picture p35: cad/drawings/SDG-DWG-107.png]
Figure 13. Making sketch of the brake band and lever


*Figure 13. Brake band and lever making sketch (SDG-DWG-107).*

**What it is and what it is made from.** A steel strip 40 x 3 mm lined with 5 mm woven brake lining; two end links of 10 mm bar; a 20 mm pivot shaft with a short inner arm and a 450 mm lever of 25 mm bar outside.

**How to make it.**

1. Cut the strip about 760 long and roll it to 340 inside diameter. Rivet the lining inside with countersunk rivets.
2. Form a loop at each end and fit a link.
3. Weld the inner arm to the pivot shaft so its end is 50 from the shaft centre; weld the lever to the shaft's outer end, rising at 62 degrees toward the rear when the brake is off. Weld a grip at the top.

**How it fits the parts next to it.** The band wraps about 245 degrees round the brake rim, open toward the lever. Its upper end links to the pivot shaft and its lower end to the inner arm (Figure 14). The pivot shaft passes through the 21 mm hole in the left cheek. With the lever down the lining stands 2 to 3 mm off the rim; lifting the lever squeezes it on.

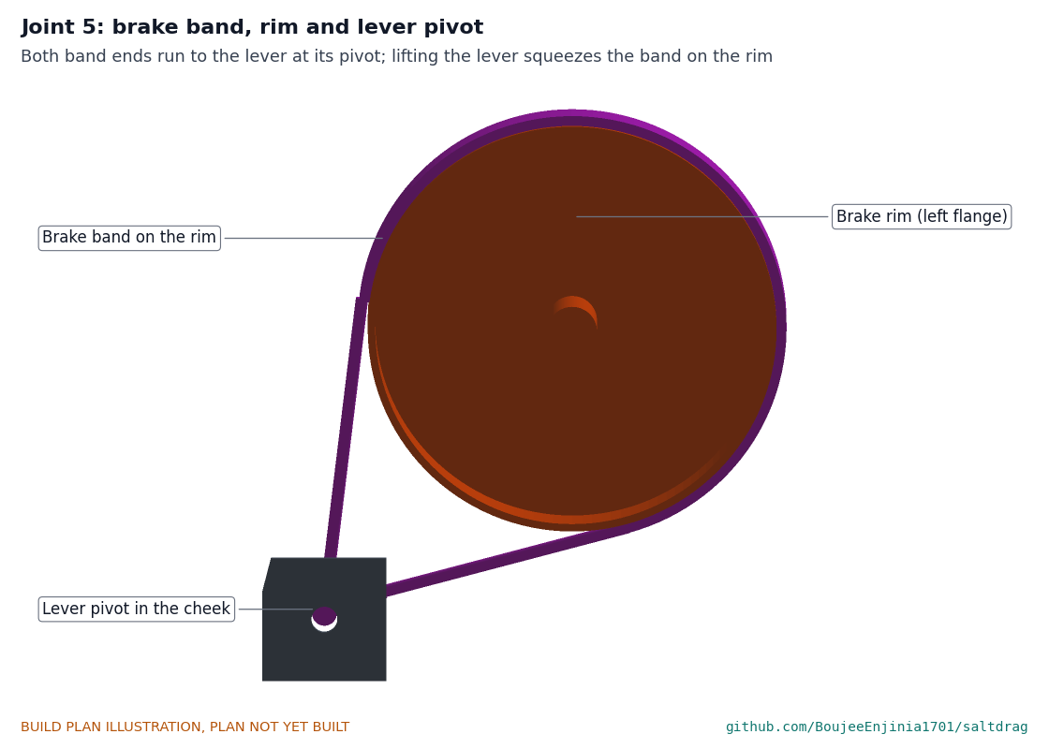
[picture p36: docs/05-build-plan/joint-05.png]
Figure 14. Joint 5: brake band, rim and lever pivot


*Figure 14. Brake band on the rim, both ends running to the lever at its pivot.*

**Check before moving on.** Lever up: the drum cannot be turned by hand at the rim. Lever down: it spins freely.

### 3.8 Gear guard (make 2)

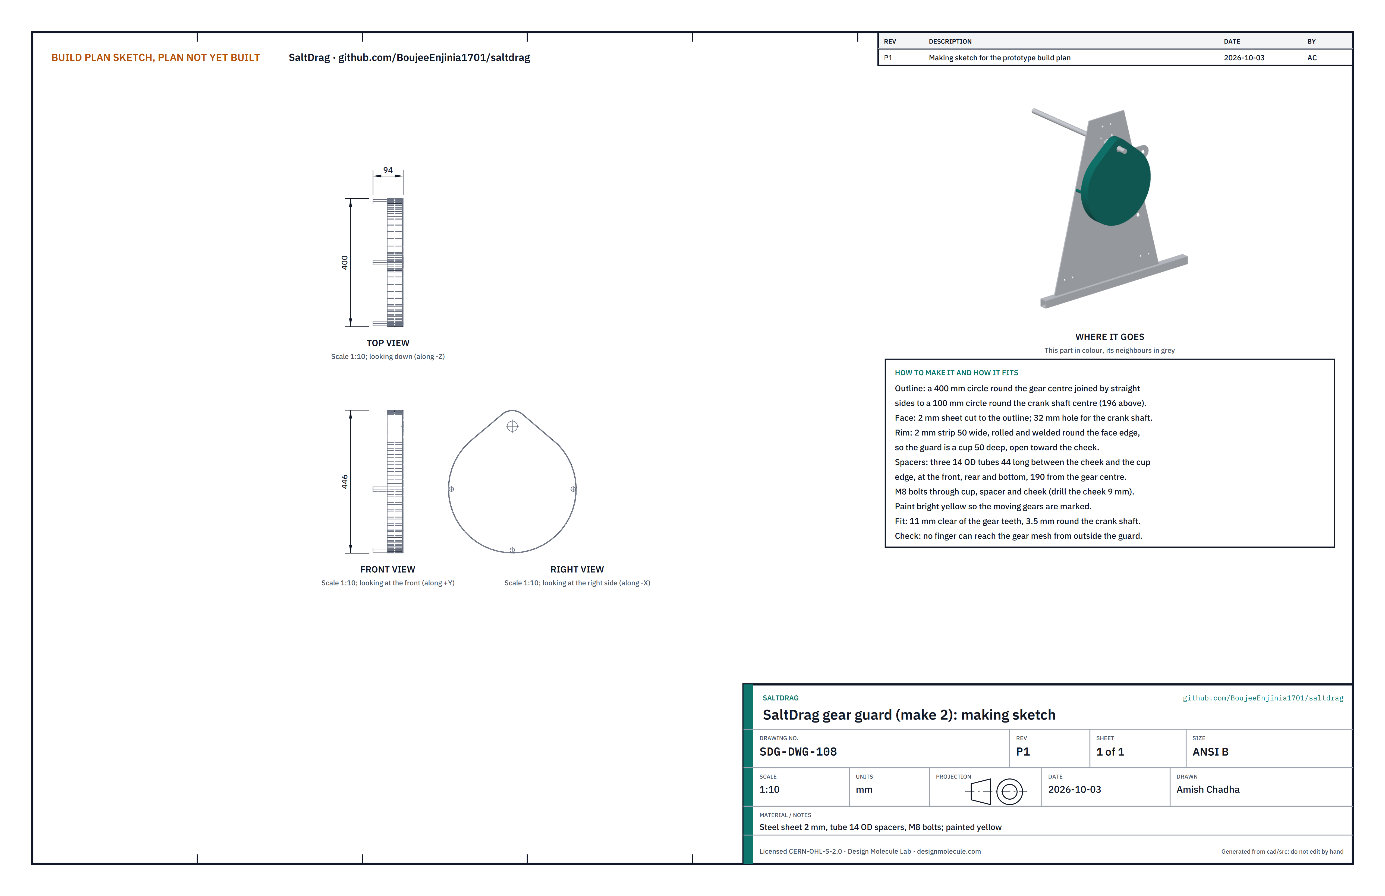
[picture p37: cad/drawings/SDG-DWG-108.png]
Figure 15. Making sketch of the gear guard


*Figure 15. Gear guard making sketch (SDG-DWG-108).*

**What it is and what it is made from.** A cup of 2 mm steel sheet over the gear and pinion, on three 14 mm tube spacers with M8 bolts. Painted bright yellow.

**How to make it.**

1. Cut the face to the outline: a 400 mm circle round the gear centre joined by straight sides to a 100 mm circle round the crank shaft centre, 196 above. Cut a 32 mm hole for the crank shaft.
2. Roll a 50 mm wide strip and weld it round the face edge, making a cup 50 deep.
3. Weld three bolt bushes inside the rim at the spacer positions (190 from the gear centre, ahead, behind and below).
4. Cut the spacers 44 long. Paint the guard yellow.

**How it fits the parts next to it.** The guard bolts to the right cheek through the spacers, its open side toward the cheek; it stands 11 clear of the gear teeth and 3.5 round the crank shaft.

**Check before moving on.** No finger can reach the gear mesh from outside the guard.

### 3.9 Bund roller saddle (make 2)

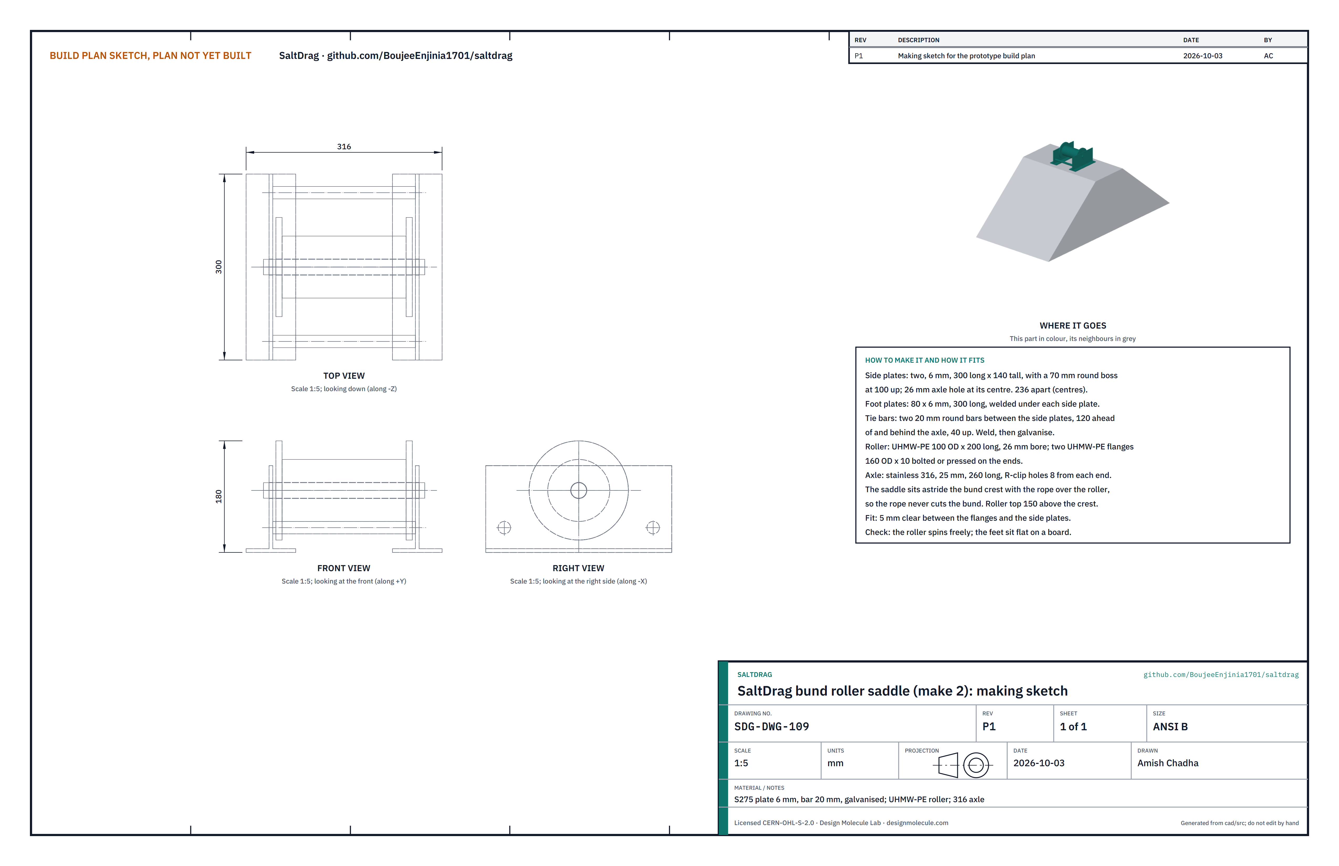
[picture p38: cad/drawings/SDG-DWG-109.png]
Figure 16. Making sketch of the bund roller saddle


*Figure 16. Bund roller saddle making sketch (SDG-DWG-109).*

**What it is and what it is made from.** Two galvanised side plates of 6 mm steel on foot plates, tied by two 20 mm bars, carrying a UHMW-PE roller 100 diameter and 200 long with two 160 mm flanges on a 25 mm stainless axle.

**How to make it.**

1. Cut two side plates 300 x 140 with a 70 mm round boss at 100 up; drill the 26 mm axle hole at its centre.
2. Weld each plate on an 80 x 6 mm foot plate 300 long.
3. Weld the two tie bars between the side plates, 120 ahead and behind the axle and 40 up, so the plates are 236 apart (centres). Galvanise.
4. Bore the roller 26 mm; fit the two flanges on its ends.
5. Cut the axle 260 long and drill 8 mm R-clip holes 8 from each end.

**How it fits the parts next to it.** The roller turns on the axle between the side plates with 5 mm each side (Figure 17). The saddle sits astride the bund crest; the rope runs over the roller top, 150 above the crest.

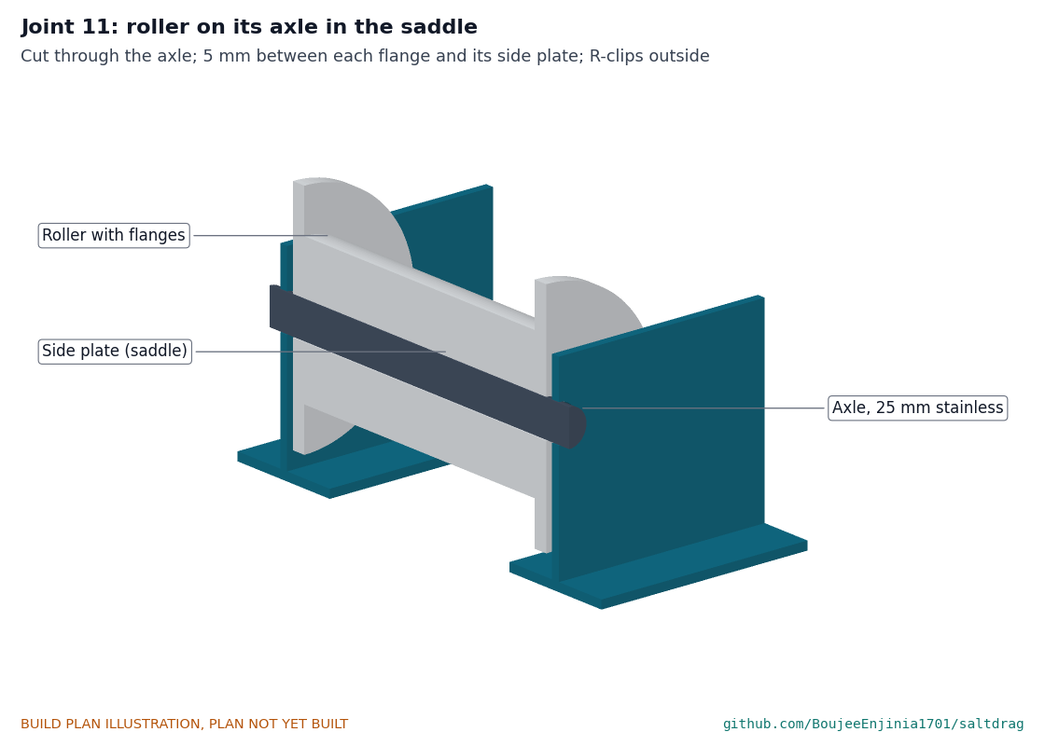
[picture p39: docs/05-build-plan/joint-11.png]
Figure 17. Joint 11: roller on its axle in the saddle


*Figure 17. Cut through the axle: roller, flanges, axle and side plates.*

**Check before moving on.** The roller spins freely; the feet sit flat on a board.

### 3.10 Rake beam

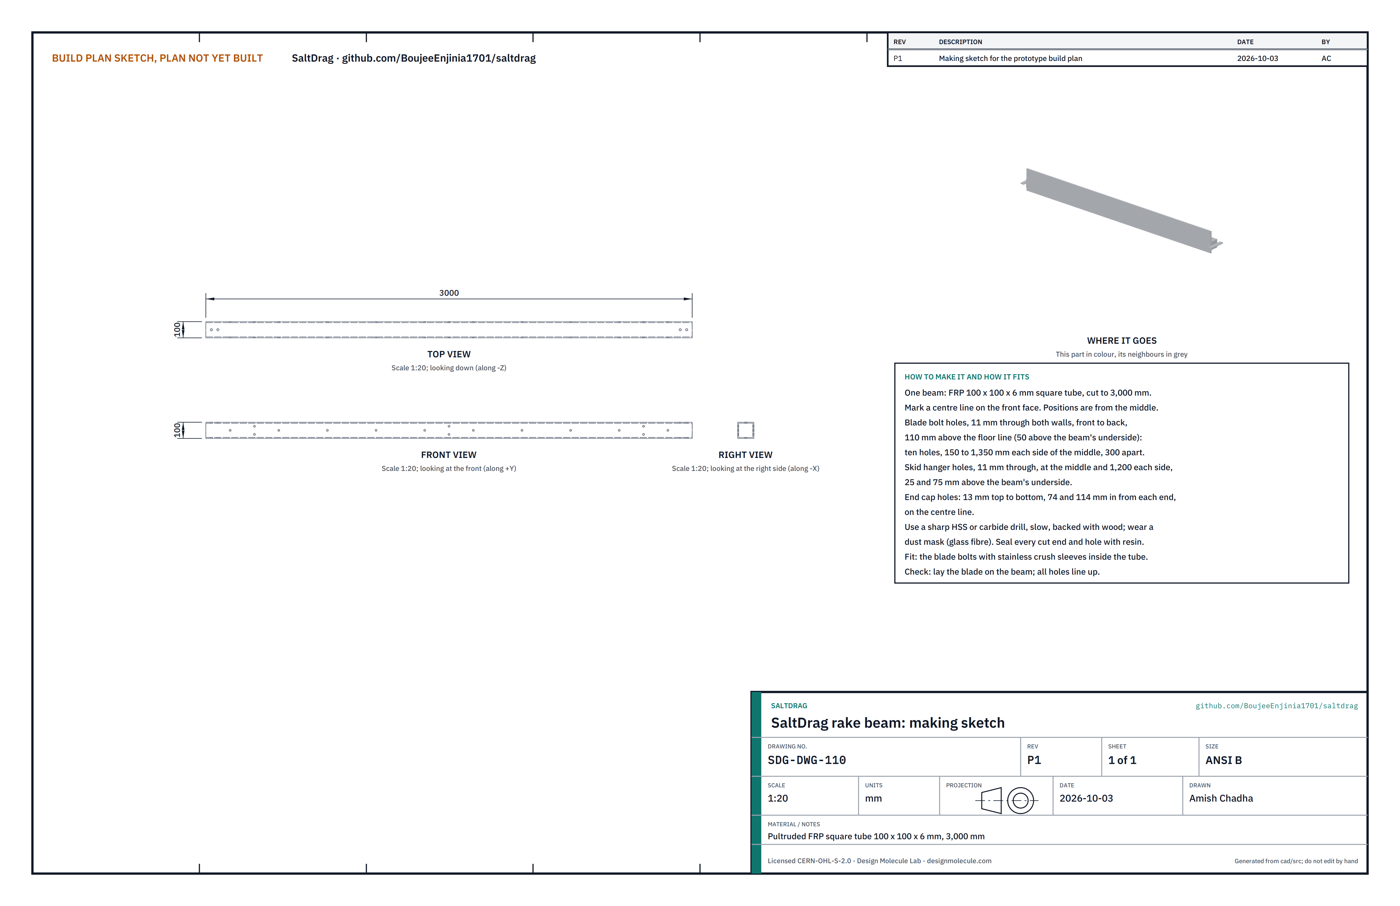
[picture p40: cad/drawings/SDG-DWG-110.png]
Figure 18. Making sketch of the rake beam


*Figure 18. Rake beam making sketch (SDG-DWG-110).*

**What it is and what it is made from.** One pultruded FRP square tube 100 x 100 x 6 mm, 3,000 long.

**How to make it.**

1. Cut to 3,000 with a fine-tooth blade. Mark a centre line on the front face; all positions are from the middle.
2. Drill the ten blade bolt holes, 11 mm through both walls front to back, 50 above the beam's underside: 150, 450, 750, 1,050 and 1,350 each side of the middle.
3. Drill the skid hanger holes, 11 mm through, at the middle and 1,200 each side, 25 and 75 above the underside.
4. Drill the end cap holes, 13 mm top to bottom, 74 and 114 in from each end.
5. Drill slowly with a sharp bit, backed with wood; wear a dust mask. Seal every cut end and hole with resin.

**How it fits the parts next to it.** The blade bolts to its front face, the skid hangers to its back face and the end caps over its ends.

**Check before moving on.** Lay the blade on the beam: every hole lines up.

### 3.11 Rake blade

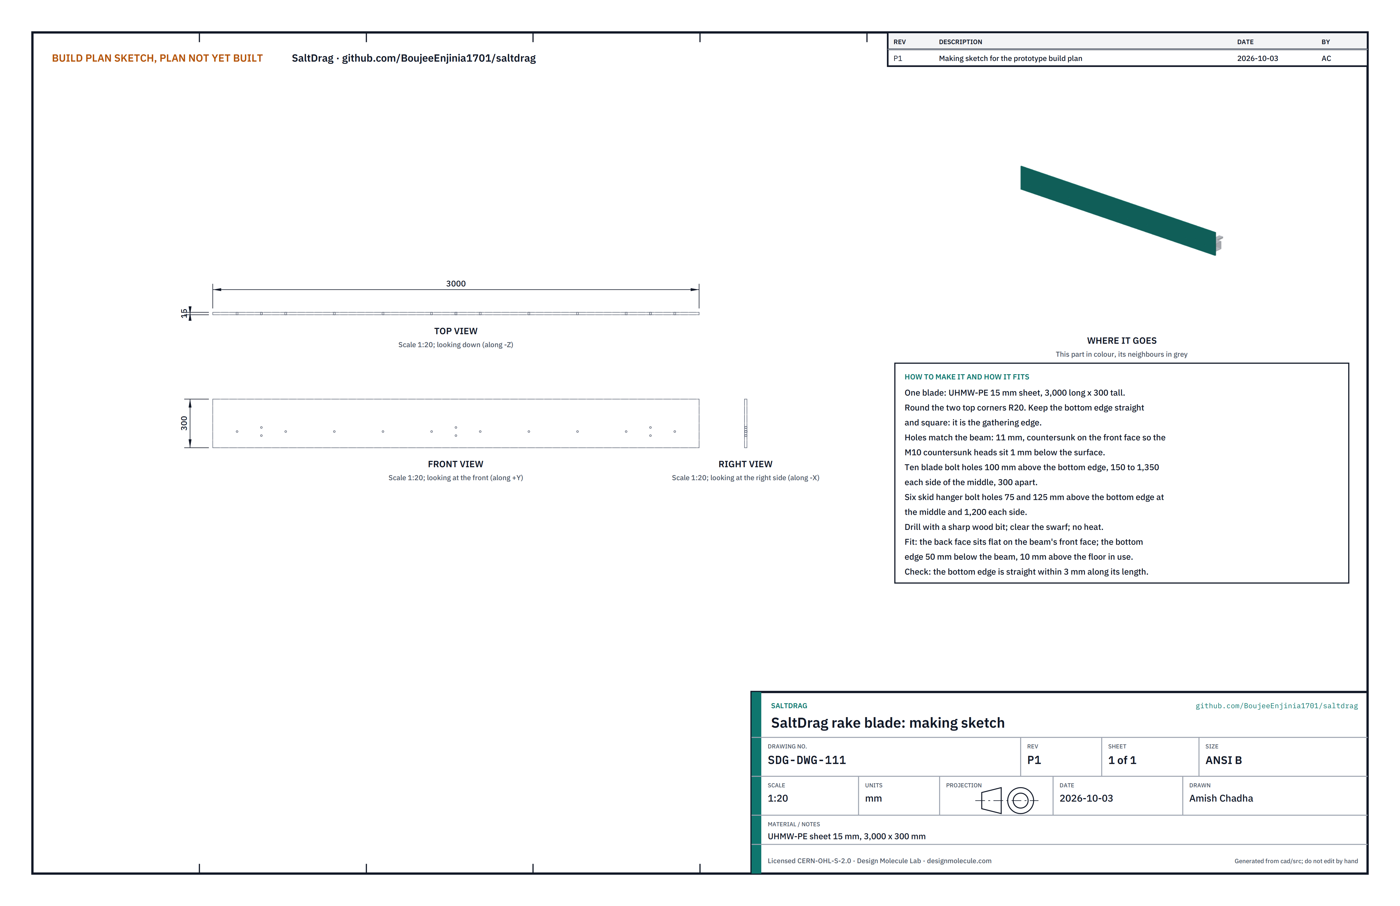
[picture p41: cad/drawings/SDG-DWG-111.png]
Figure 19. Making sketch of the rake blade


*Figure 19. Rake blade making sketch (SDG-DWG-111).*

**What it is and what it is made from.** UHMW-PE sheet 15 mm, 3,000 x 300.

**How to make it.**

1. Cut to size. Round the top corners to 20 radius; keep the bottom edge straight and square, as it is the gathering edge.
2. Drill the ten blade bolt holes 11 mm, 100 above the bottom edge, at the beam's positions, and countersink them on the front face so M10 countersunk heads sit 1 mm below the surface.
3. Drill the six skid hanger bolt holes 75 and 125 above the bottom edge at the middle and 1,200 each side, countersunk the same way.

**How it fits the parts next to it.** The back face sits flat on the beam's front face, its bottom edge 50 below the beam. M10 countersunk bolts pass through blade and beam, with a stainless crush sleeve inside the tube and a nyloc nut at the back (Figure 20).

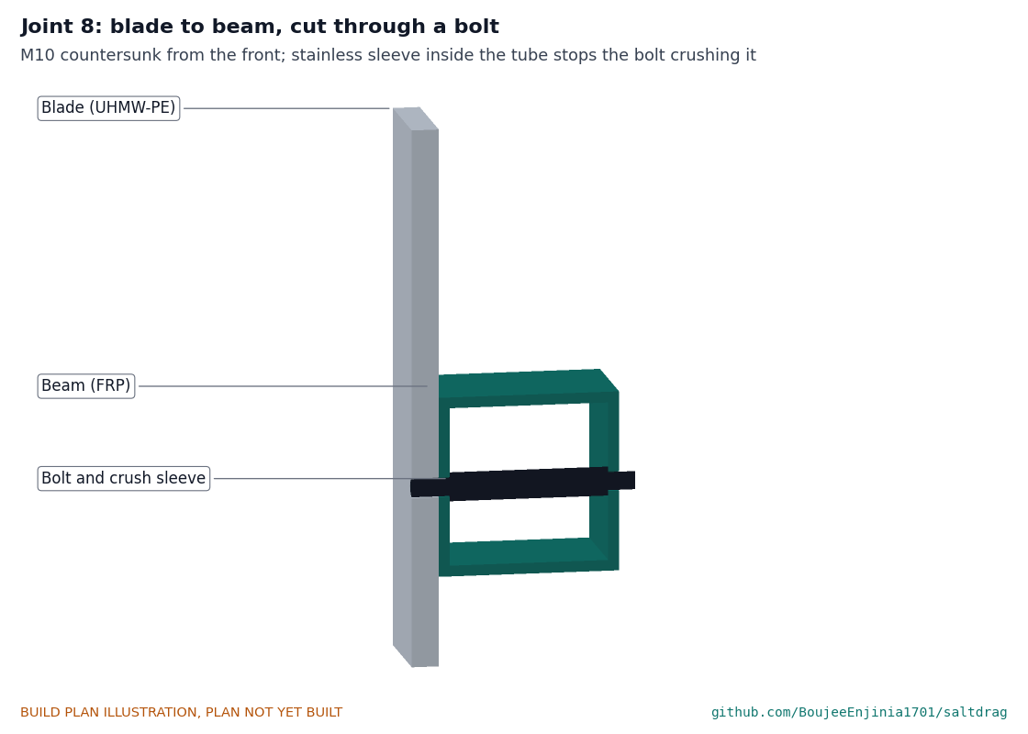
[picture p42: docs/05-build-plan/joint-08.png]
Figure 20. Joint 8: blade to beam, cut through a bolt


*Figure 20. Cut through a blade bolt: blade, beam walls and crush sleeve.*

**Check before moving on.** The bottom edge is straight within 3 mm over its length.

### 3.12 Skids and hangers (make 3)

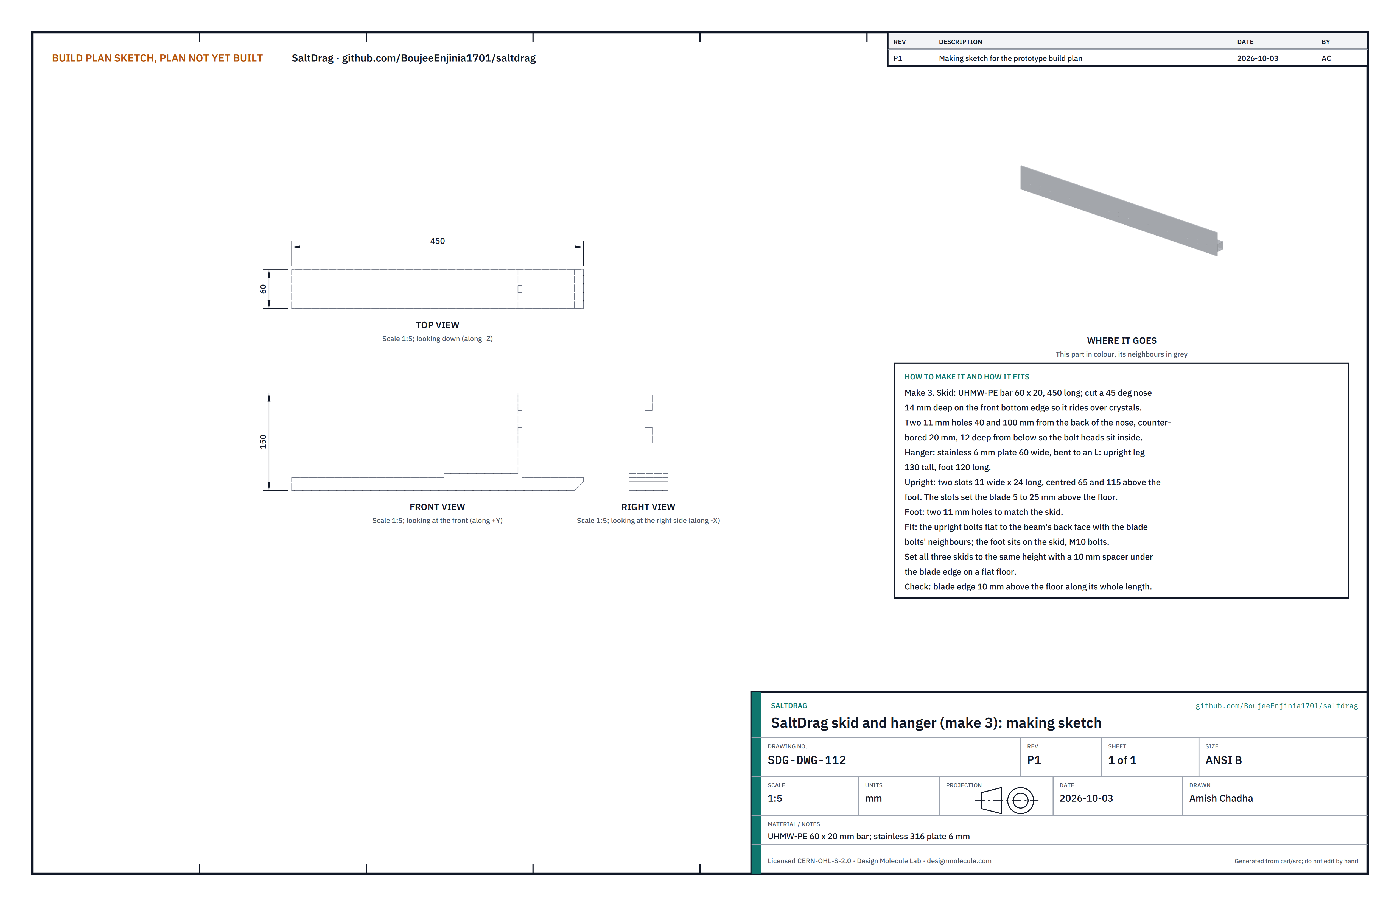
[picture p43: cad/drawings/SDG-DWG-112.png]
Figure 21. Making sketch of a skid and hanger


*Figure 21. Skid and hanger making sketch (SDG-DWG-112).*

**What it is and what it is made from.** A UHMW-PE skid 60 x 20 x 450 and an L-shaped hanger of 6 mm stainless 316 plate.

**How to make it.**

1. Cut the skid 450 long with a 45 degree nose, 14 mm deep, on its front bottom edge.
2. Drill two 11 mm holes 40 and 100 behind the nose, counterbored 20 mm and 12 deep from below so the bolt heads sit inside.
3. Bend the hanger plate, 60 wide, to an L: an upright leg 130 tall and a foot 120 long.
4. Cut two slots 11 wide and 24 long in the upright, centred 65 and 115 above the foot; drill two 11 mm holes in the foot to match the skid.

**How it fits the parts next to it.** The upright bolts flat to the beam's back face through its slots; the foot sits on the skid with two M10 bolts (Figure 22). The slots set the blade 5 to 25 mm above the floor.

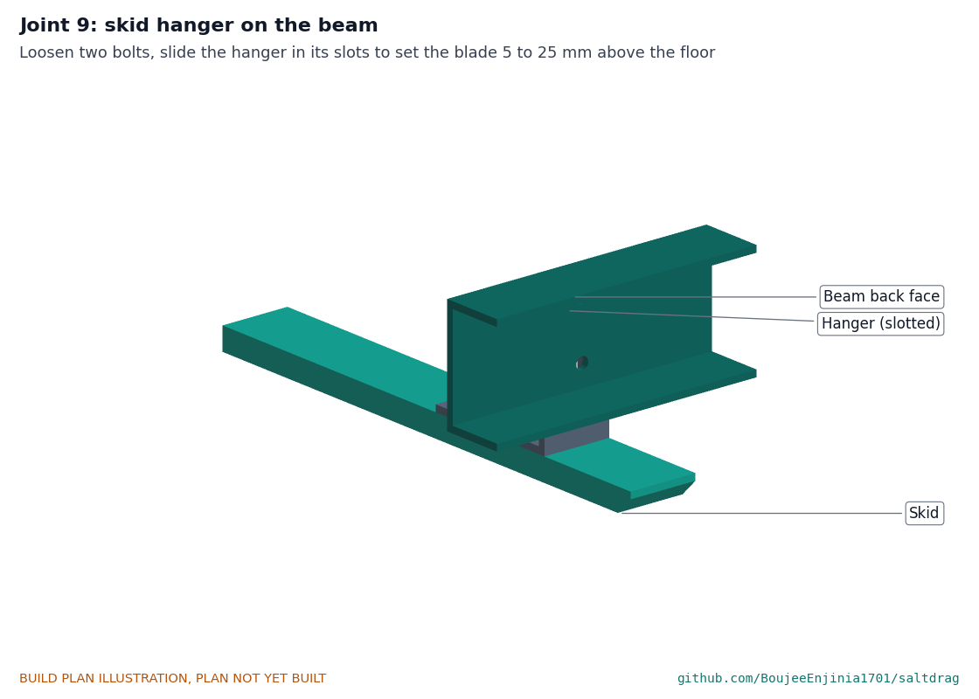
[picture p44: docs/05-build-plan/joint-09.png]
Figure 22. Joint 9: skid hanger on the beam


*Figure 22. Skid hanger on the beam's back face, slots for height.*

**Check before moving on.** With all three skids on a flat floor and a 10 mm spacer under the blade, the edge is 10 mm up along its whole length.

### 3.13 End caps with eye plates (make 2)

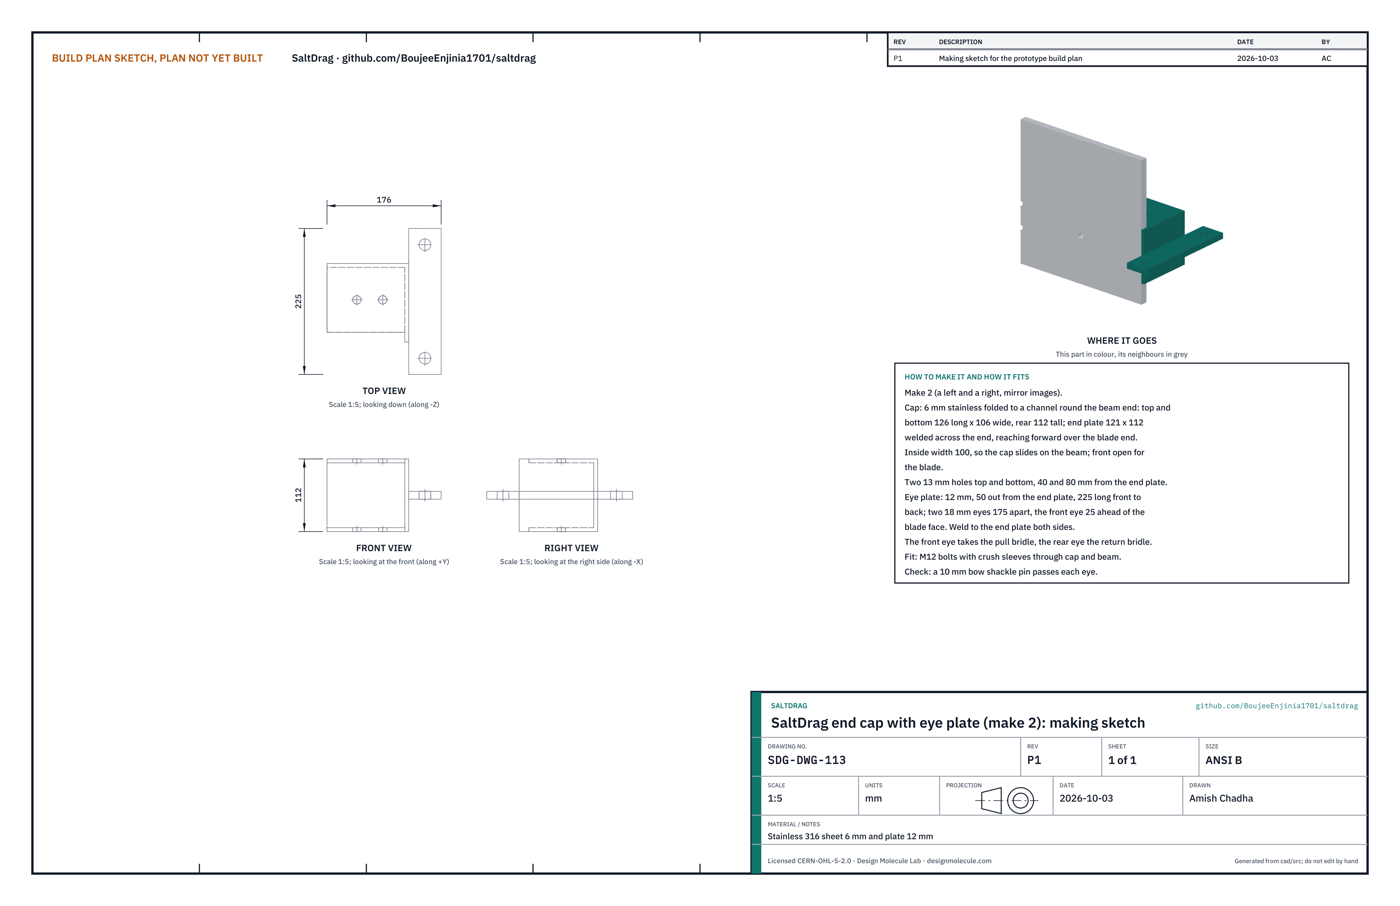
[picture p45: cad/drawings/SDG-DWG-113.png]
Figure 23. Making sketch of an end cap


*Figure 23. End cap making sketch (SDG-DWG-113).*

**What it is and what it is made from.** A left and a right, mirror images, in stainless 316: a 6 mm sheet channel round the beam end with an end plate, and a 12 mm eye plate.

**How to make it.**

1. Fold the channel: top and bottom 126 long by 106 wide, rear 112 tall, inside width 100 so it slides on the beam; the front stays open for the blade.
2. Weld the end plate (121 x 112) across the end, reaching forward over the blade end.
3. Drill two 13 mm holes through top and bottom, 40 and 80 from the end plate.
4. Cut the eye plate 225 long front to back, standing 50 out from the end plate, with two 18 mm eyes 175 apart, the front eye 25 ahead of the blade face. Weld it to the end plate on both sides.

**How it fits the parts next to it.** The cap slides over the beam end, two M12 bolts with crush sleeves through cap and beam. The front eye takes the pull bridle and the rear eye the return bridle, each with a bow shackle (Figure 24).

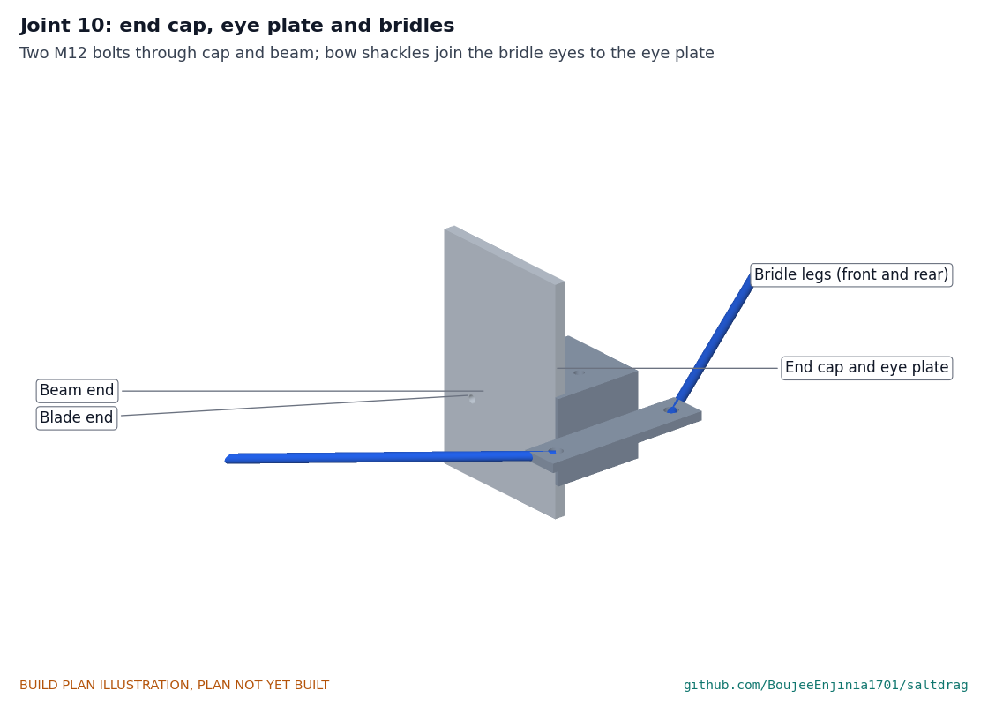
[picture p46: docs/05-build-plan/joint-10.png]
Figure 24. Joint 10: end cap, eye plate and bridles


*Figure 24. End cap on the beam end, bridle legs shackled to the eyes.*

**Check before moving on.** A 10 mm bow shackle pin passes each eye.

### 3.14 Bought components

- **Spur gear (2):** module 4, 84 teeth, 30 mm face, C45, webbed; ordered bored 40 mm with a 12 mm keyway and set screw.
- **Flange bearings (8):** four-bolt, stainless insert in a thermoplastic housing; four 40 mm bore (102 mm bolt square), four 25 mm bore (70 mm bolt square).
- **Ground anchors (4):** helical, 20 mm rod 1.0 m long, one 150 mm helix, forged eye, galvanised.
- **Chains and turnbuckles (4 sets):** 8 mm grade 30 galvanised chain 1.4 m, M16 hook-and-eye turnbuckle, two 10 mm bow shackles each. Working load limits at least 7.8 kN (chain), 6 kN (turnbuckle).
- **Pull ropes (2):** 12 mm polyester double braid, 45 m, minimum breaking strength at least 25 kN, with a certificate; eye splice and thimble at the rake end, plain whipped end at the drum.
- **Bridles (2):** two 12 mm polyester legs about 2.5 m with spliced thimble eyes to a 1 t swivel; three 10 mm bow shackles each.
- **Fasteners:** stainless 316 M10 and M12 bolts, nyloc nuts, washers and 16 x 2 mm crush sleeves for the rake; galvanised M10, M12 and M8 bolts for the capstans.
- **Rope dampers (2), ballast bags and straps (2), maintenance kit:** as listed in the bill of materials. Fill the ballast bags on site with about 24 kg of salt each.

## 4. Putting it together

In each picture the parts already fitted are grey and the part being fitted is in colour, with an arrow showing the way it goes in. Build both capstans the same way.

### Step 1: cross tubes onto the left side frame

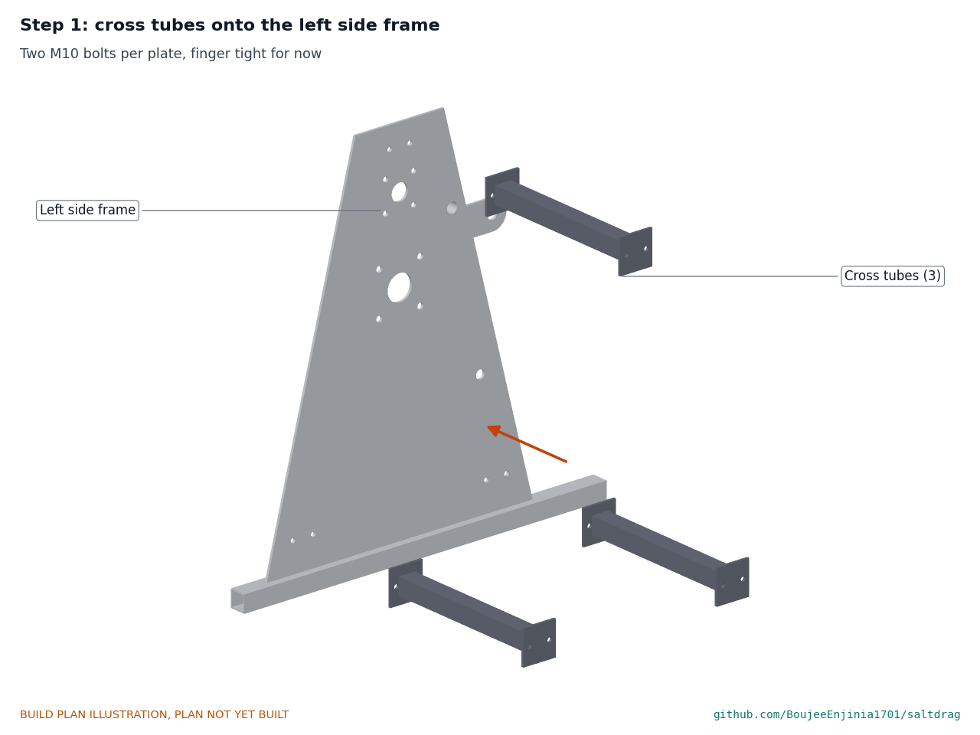
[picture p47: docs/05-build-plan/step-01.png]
Step 1


Two M10 bolts per plate, finger tight.

### Step 2: drum shaft into the left cheek

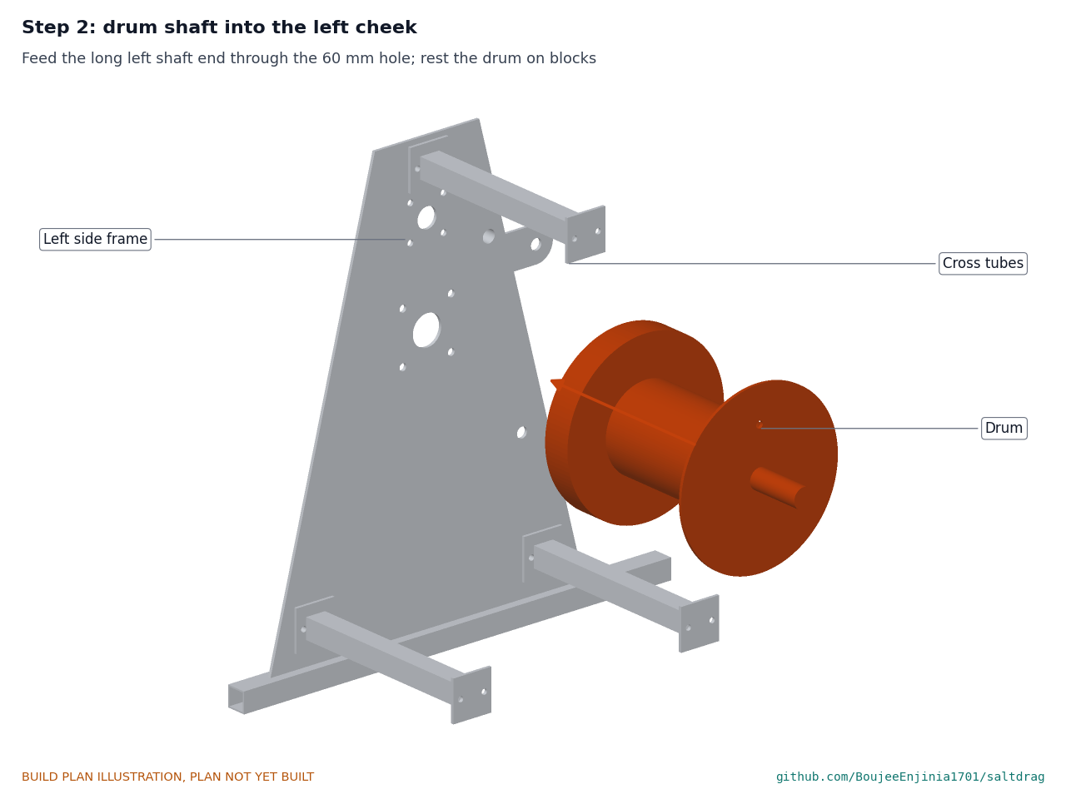
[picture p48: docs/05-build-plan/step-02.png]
Step 2


Feed the drum's long left shaft end through the 60 mm hole and rest the drum on blocks so the shaft sits central in the hole.

### Step 3: right side frame on

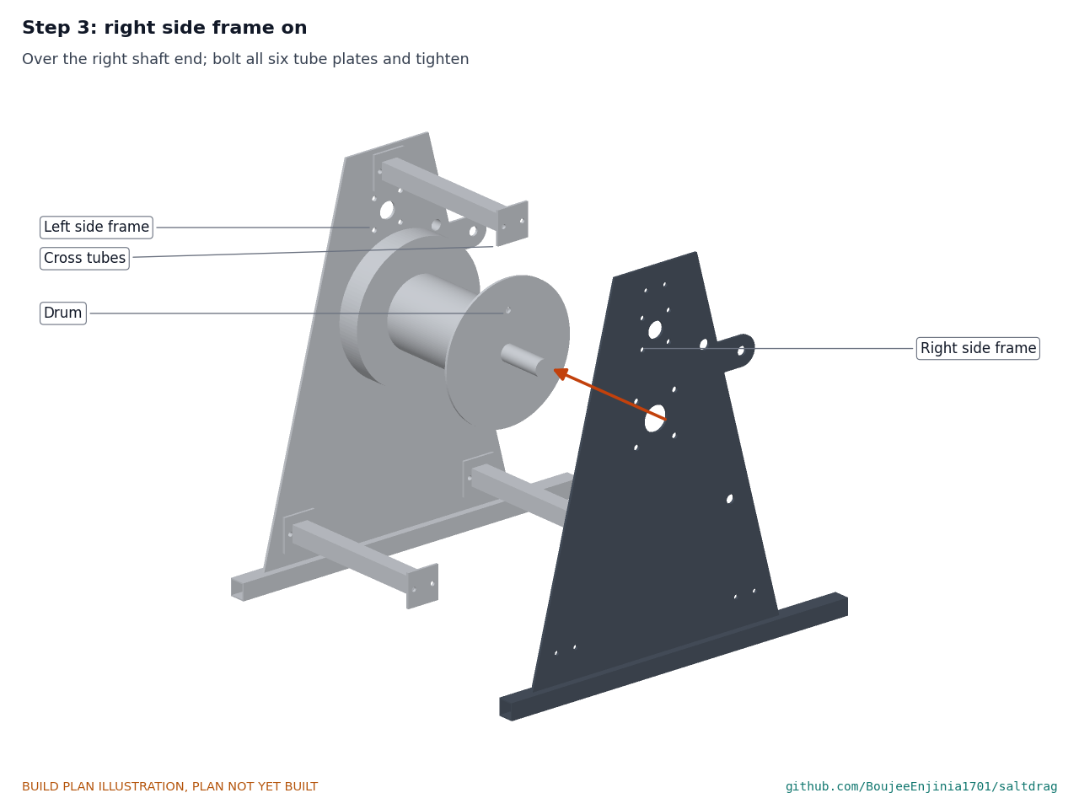
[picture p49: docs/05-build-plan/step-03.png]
Step 3


Over the right shaft end and onto the three tube plates; bolt all six plates and tighten.

### Step 4: drum bearings

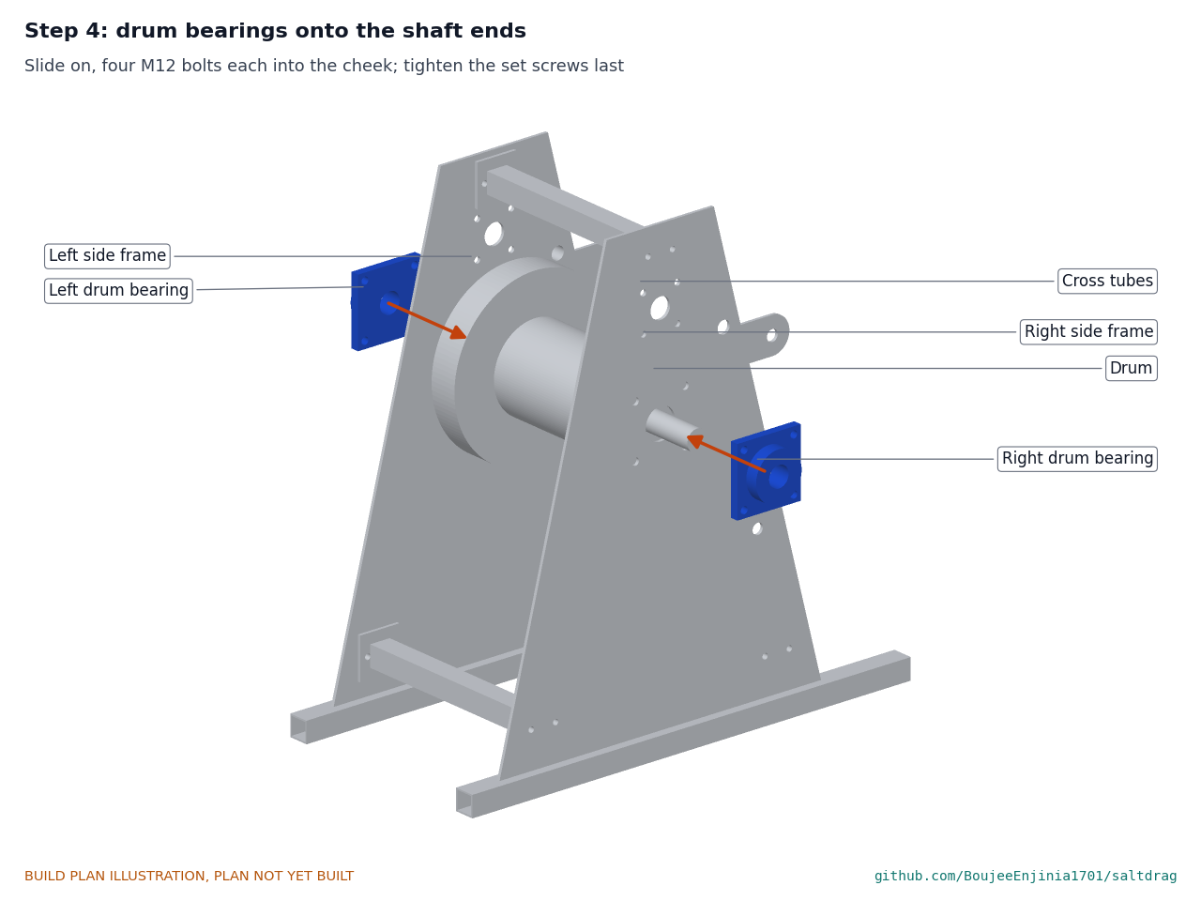
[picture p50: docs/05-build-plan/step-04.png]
Step 4


Slide a 40 mm bearing onto each shaft end, four M12 bolts into the cheek each. Turn the drum, then tighten the set screws.

### Step 5: ratchet wheel and gear

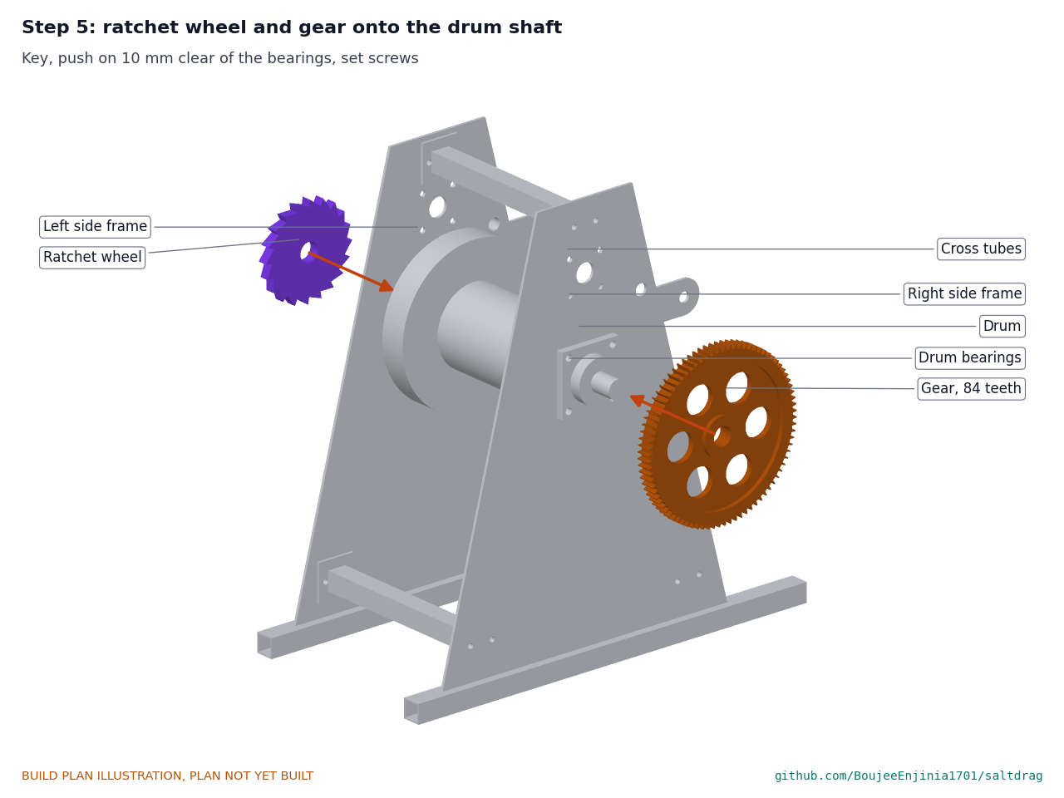
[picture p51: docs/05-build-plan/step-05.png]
Step 5


Key the ratchet wheel onto the left shaft end and the gear onto the right, each 10 clear of its bearing; tighten the set screws.

### Step 6: crank shaft, its bearings and the pinion

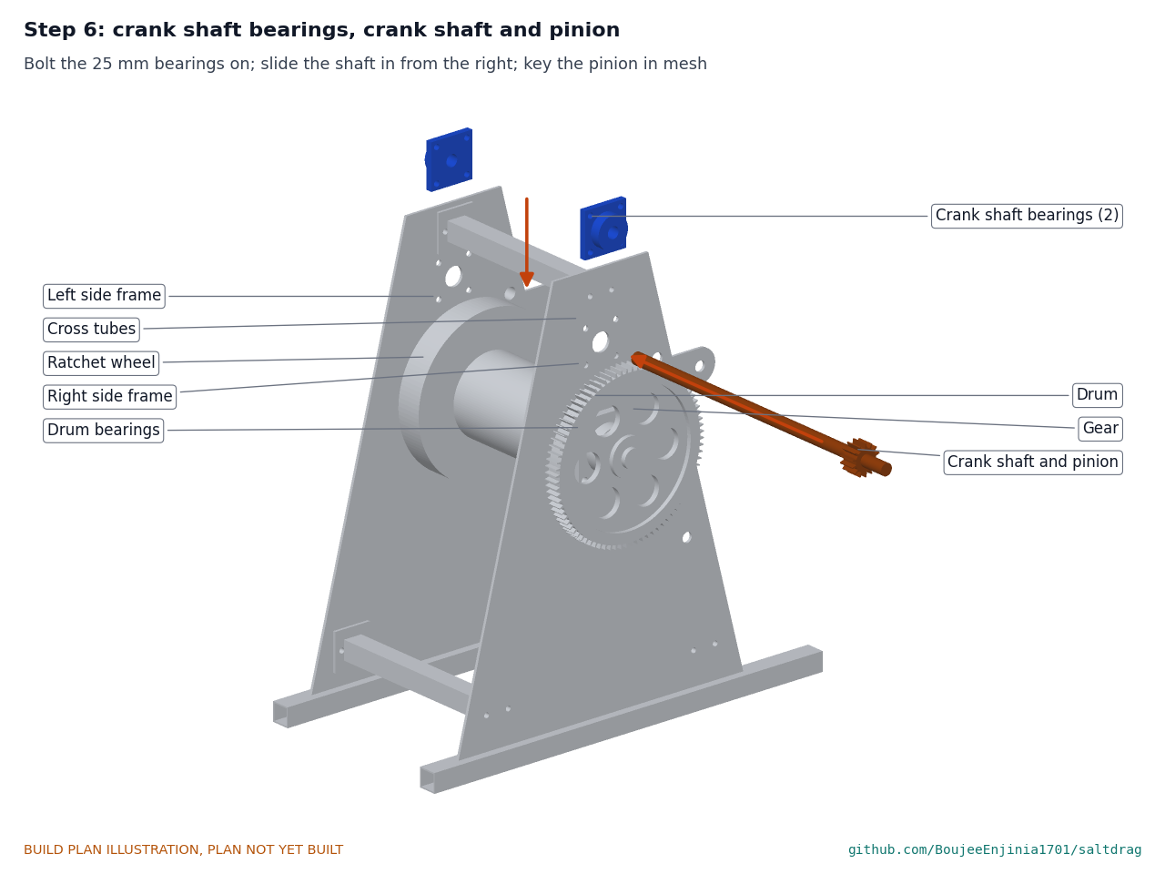
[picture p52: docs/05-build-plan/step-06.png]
Step 6


Bolt the two 25 mm bearings to the cheeks, slide the crank shaft in from the right, key the pinion on in line with the gear and lock it. Grease the mesh.

### Step 7: pawl

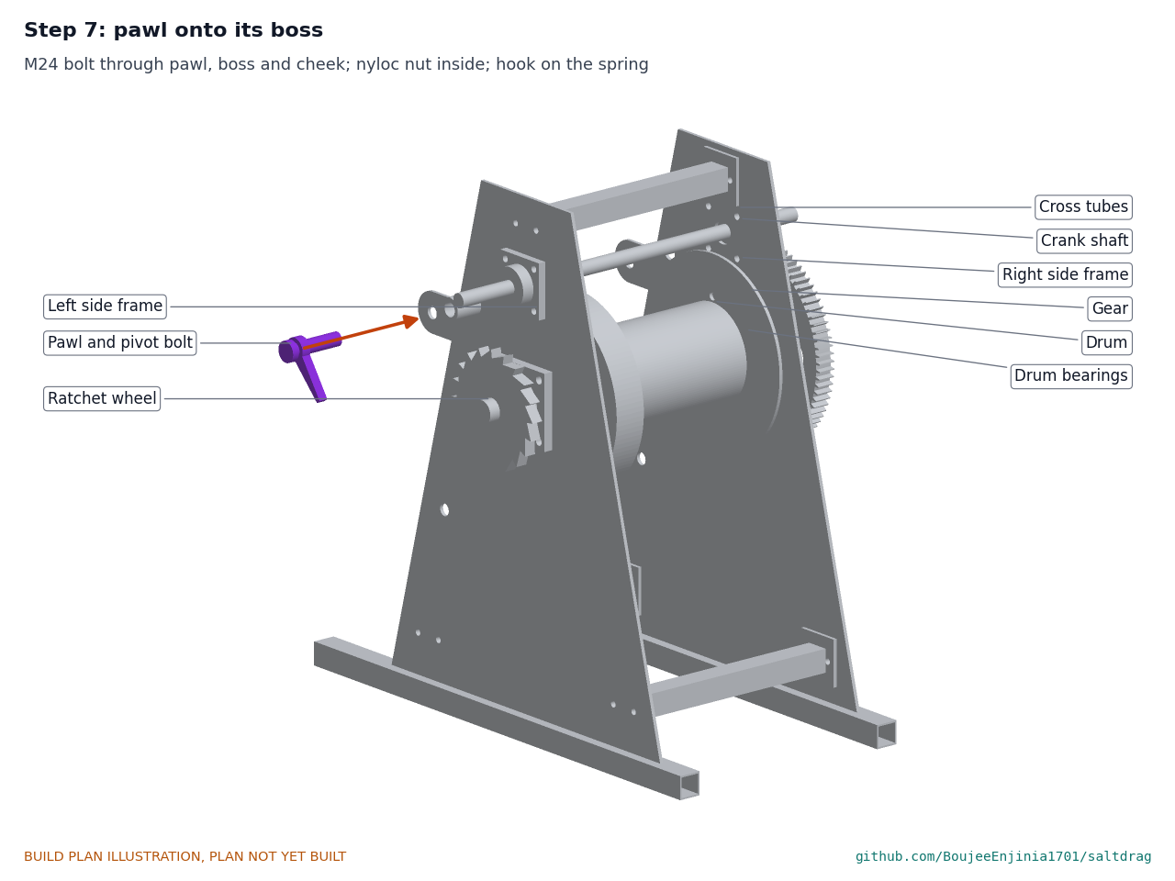
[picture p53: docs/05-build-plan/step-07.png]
Step 7


M24 bolt through pawl, boss and cheek; nyloc nut inside, snug so the pawl swings freely. Hook on the spring.

### Step 8: brake band and lever

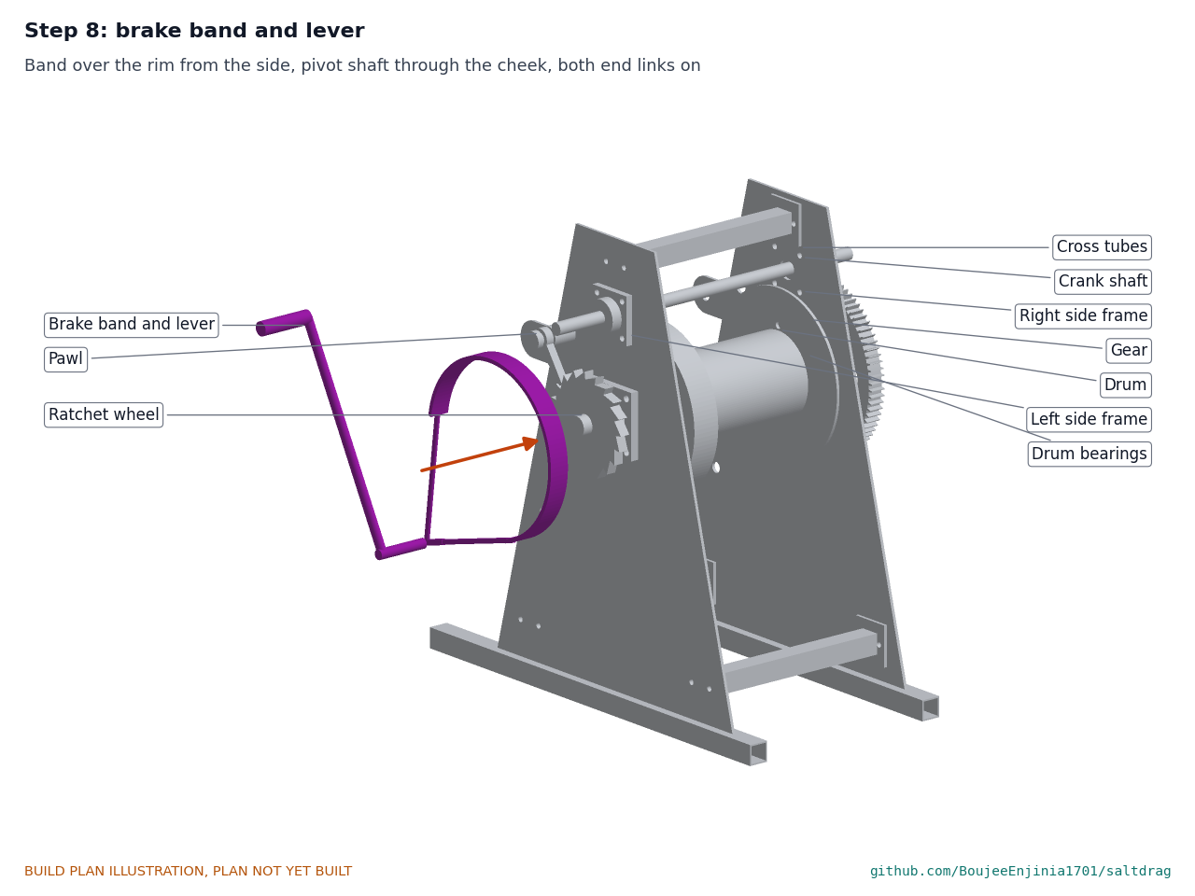
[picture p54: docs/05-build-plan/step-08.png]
Step 8


Slip the band over the brake rim from the side, pass the pivot shaft through the cheek, fit both end links. Set the lining 2 to 3 mm off the rim with the lever down.

### Step 9: gear guard

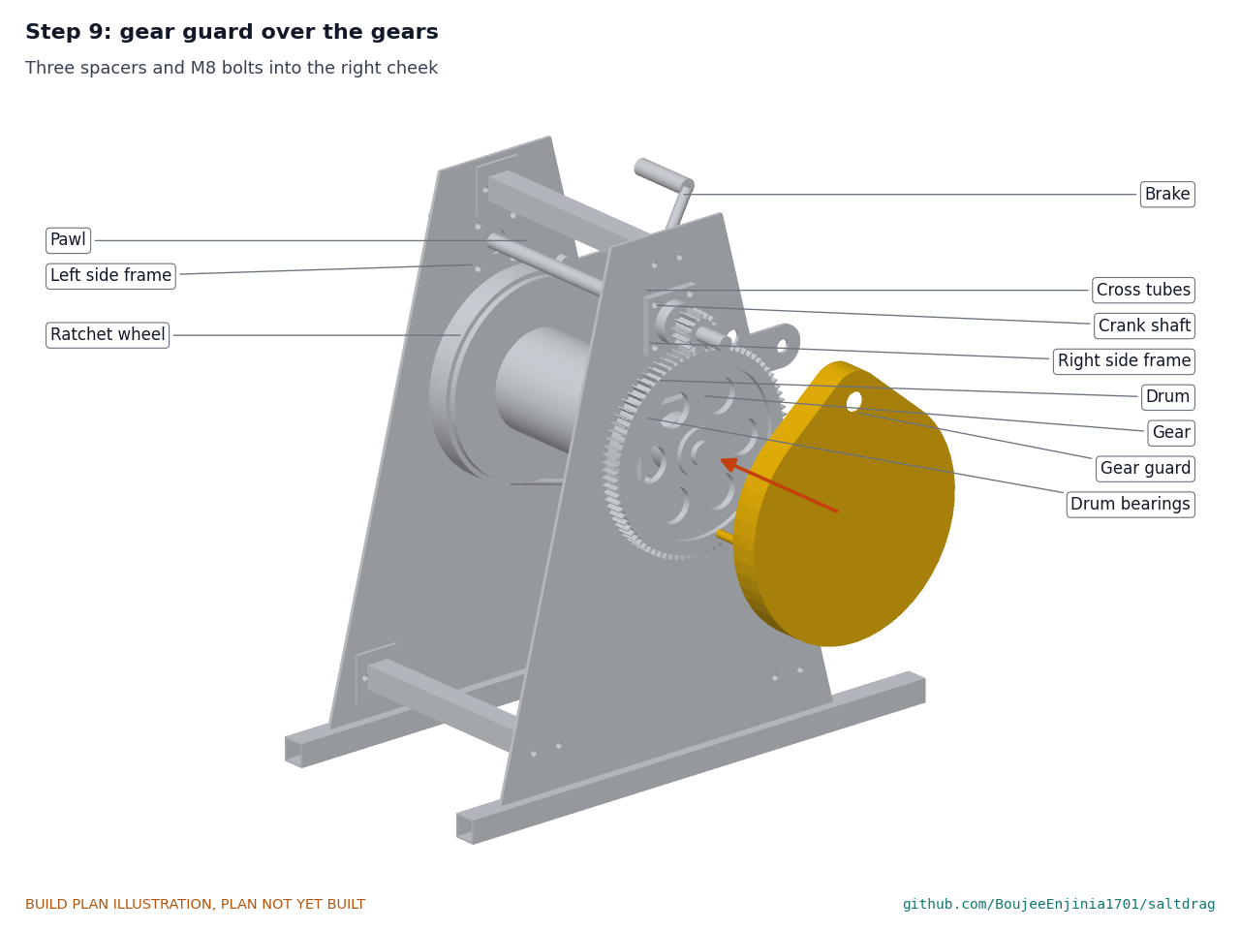
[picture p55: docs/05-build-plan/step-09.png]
Step 9


Three spacers and M8 bolts into the right cheek.

**Hold point.** Do not fit the crank handles until the guard is on.

### Step 10: crank handles

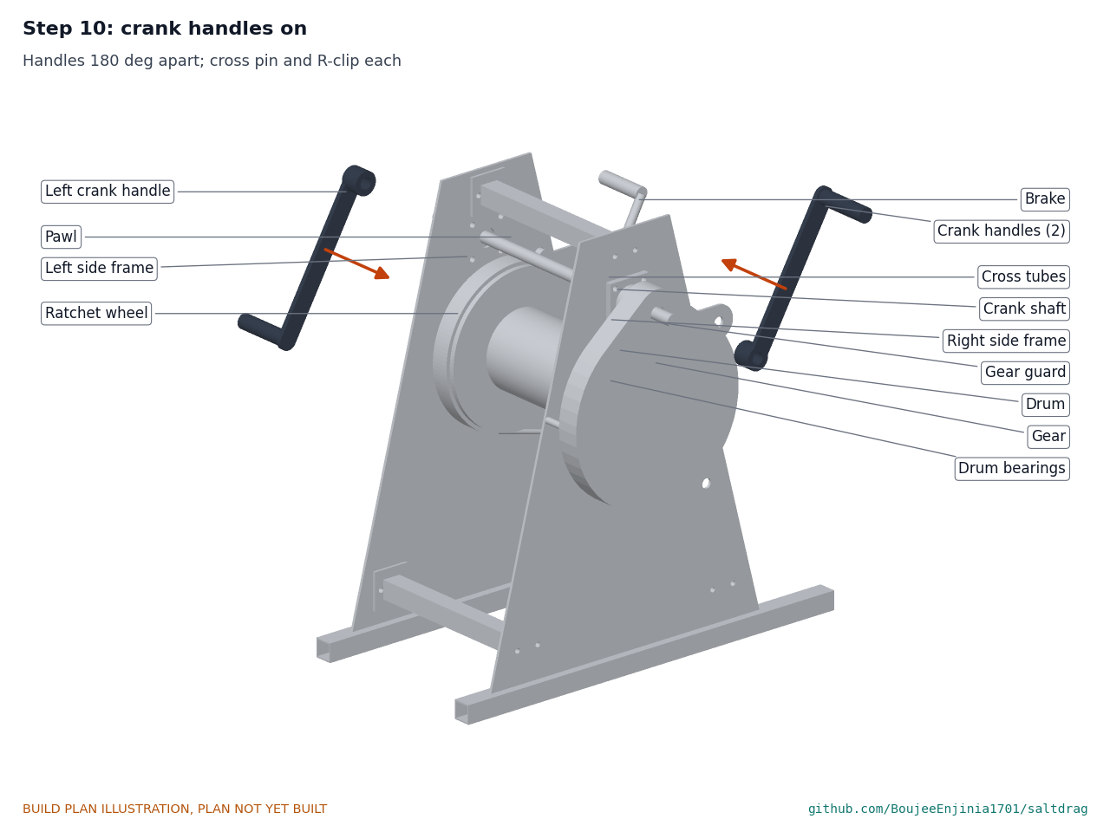
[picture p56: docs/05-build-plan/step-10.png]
Step 10


Handles 180 degrees apart; cross pin and R-clip each.

### Step 11: rope onto the drum

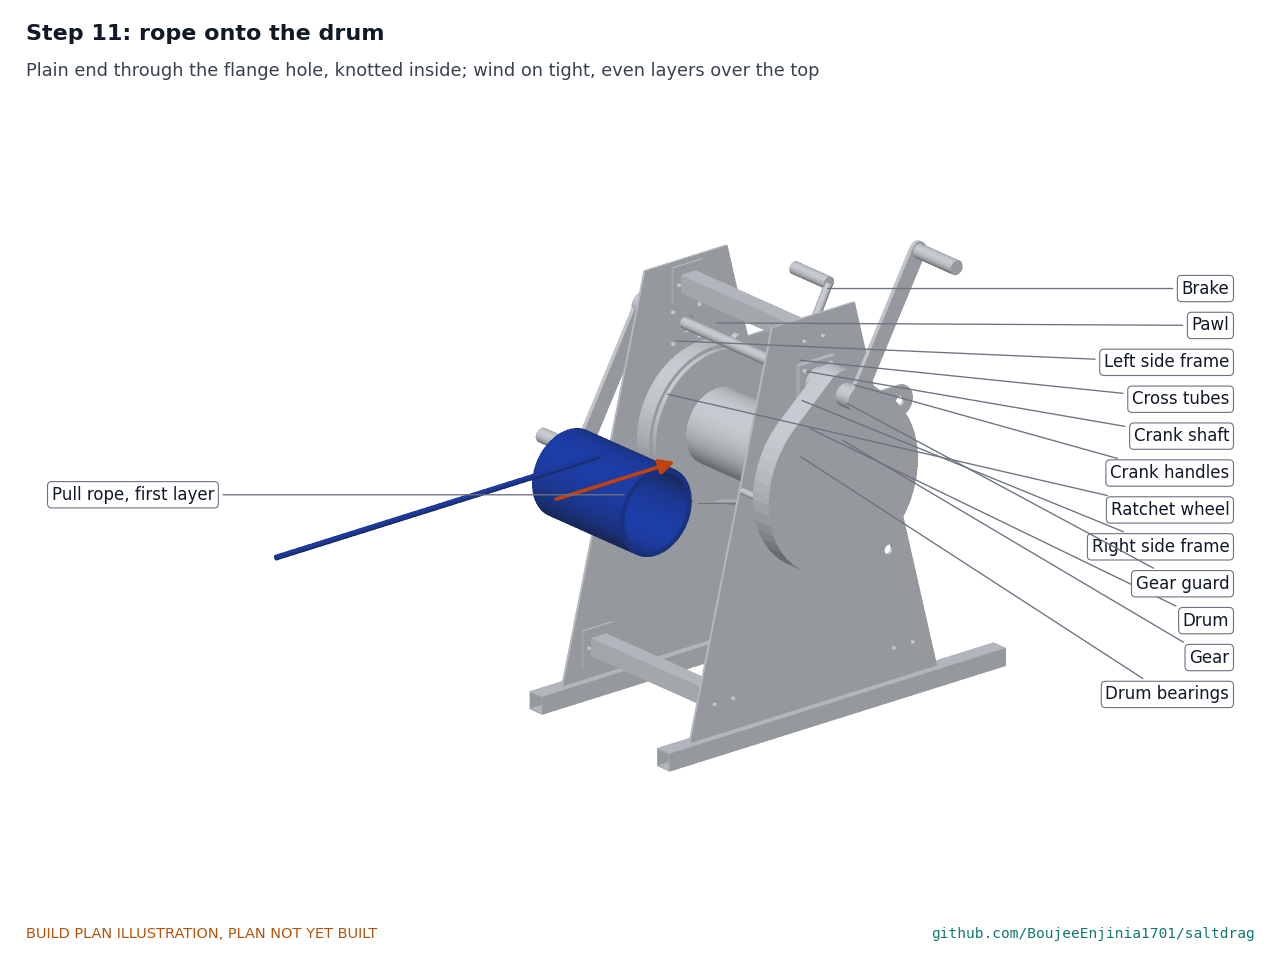
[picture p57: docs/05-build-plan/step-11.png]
Step 11


Pass the plain end through the hole in the right flange and knot it inside; leave five dead turns that are never unwound. Wind the rope on under light tension in even layers, leaving the drum over the top toward the pan.

### Step 12: blade onto the beam

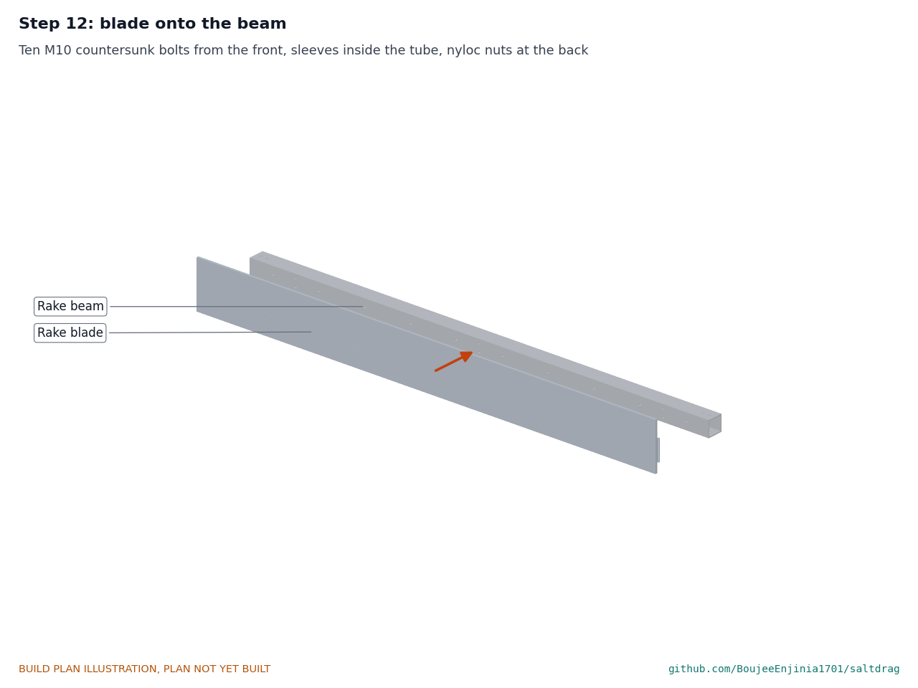
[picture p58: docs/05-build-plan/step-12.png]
Step 12


Ten M10 countersunk stainless bolts from the front, crush sleeves inside the tube, nyloc nuts at the back. Tighten until the sleeves bear; do not crush the FRP.

### Step 13: skids

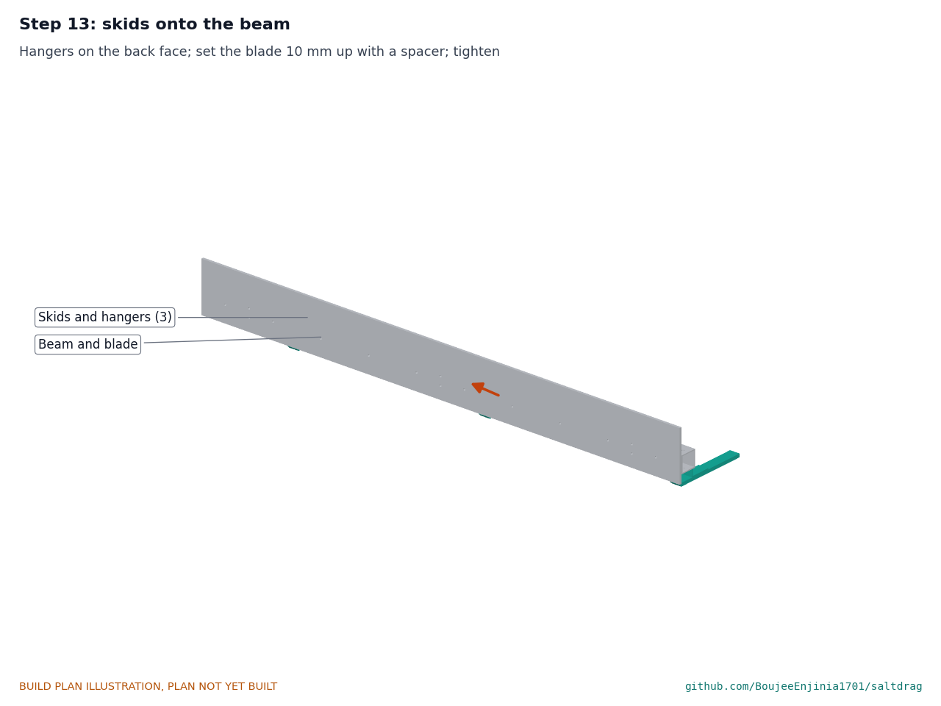
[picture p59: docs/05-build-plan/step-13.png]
Step 13


Hangers on the back face through their slots, skids on the hanger feet. Set the blade 10 mm up with a spacer and tighten.

### Step 14: end caps and bridles

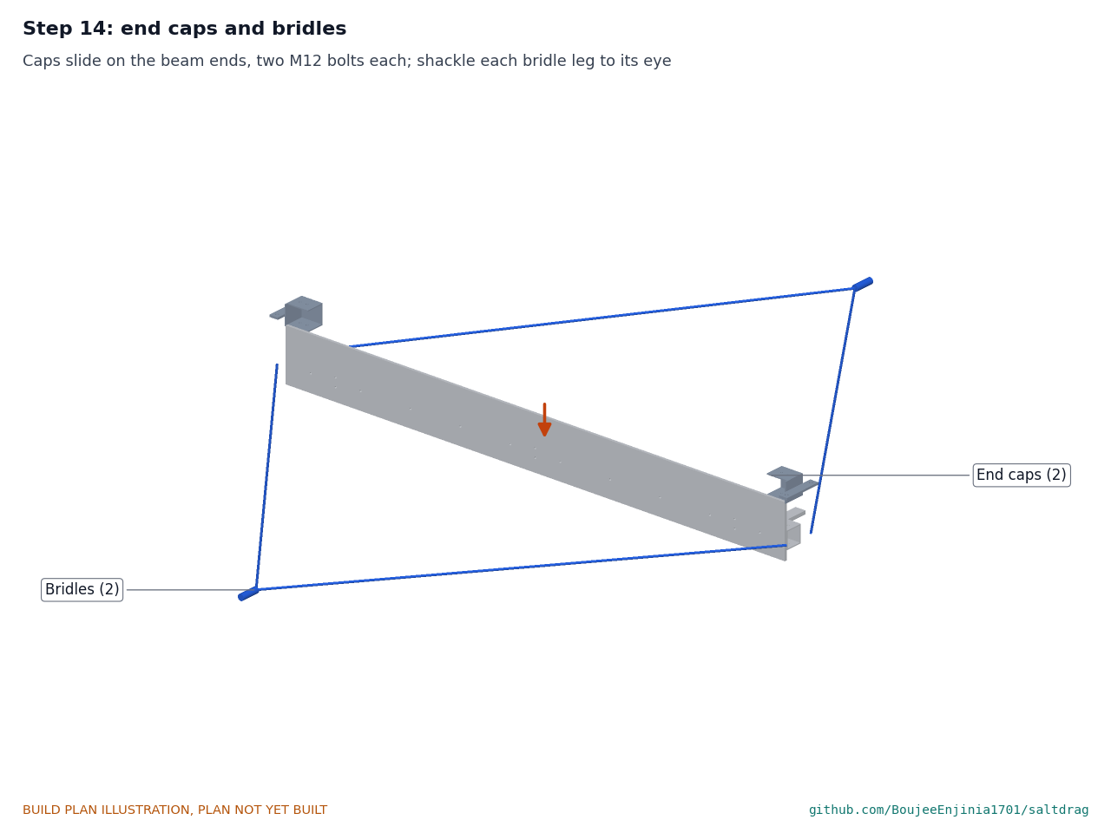
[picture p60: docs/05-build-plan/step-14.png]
Step 14


Slide the caps on the beam ends, two M12 bolts each. Shackle the pull bridle legs to the front eyes and the return bridle legs to the rear eyes; mouse each shackle pin with wire.

### Step 15: roller into its saddle

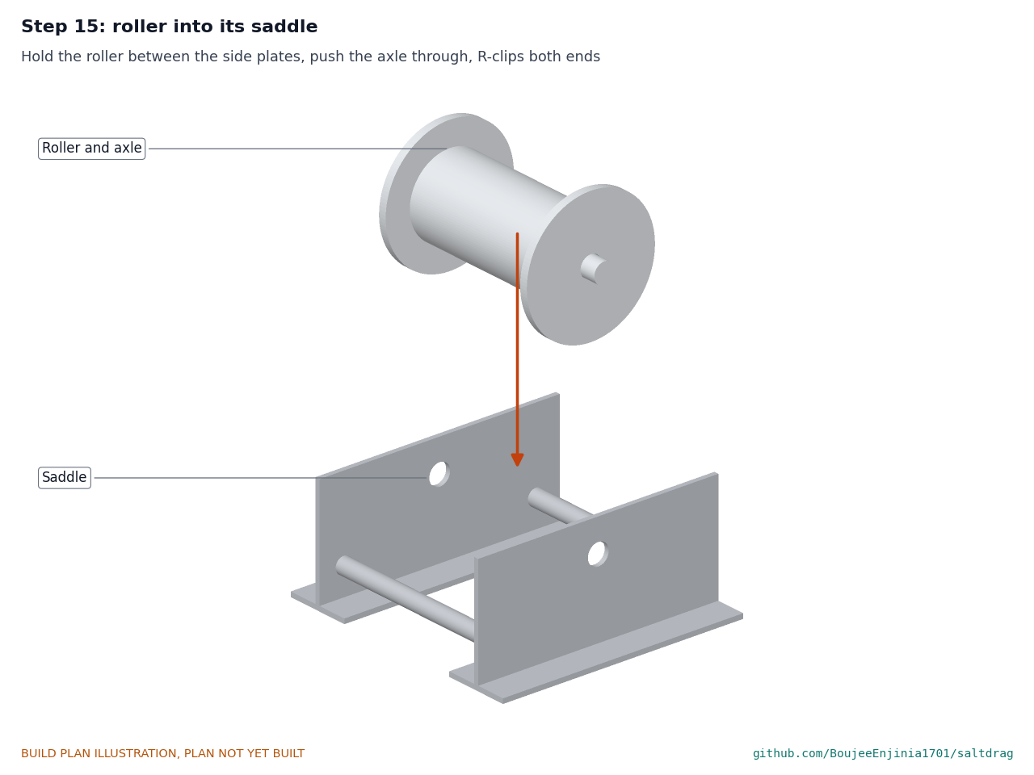
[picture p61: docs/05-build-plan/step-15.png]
Step 15


Hold the roller between the side plates, push the axle through, fit both R-clips.

### Step 16: capstan behind the bund and anchored

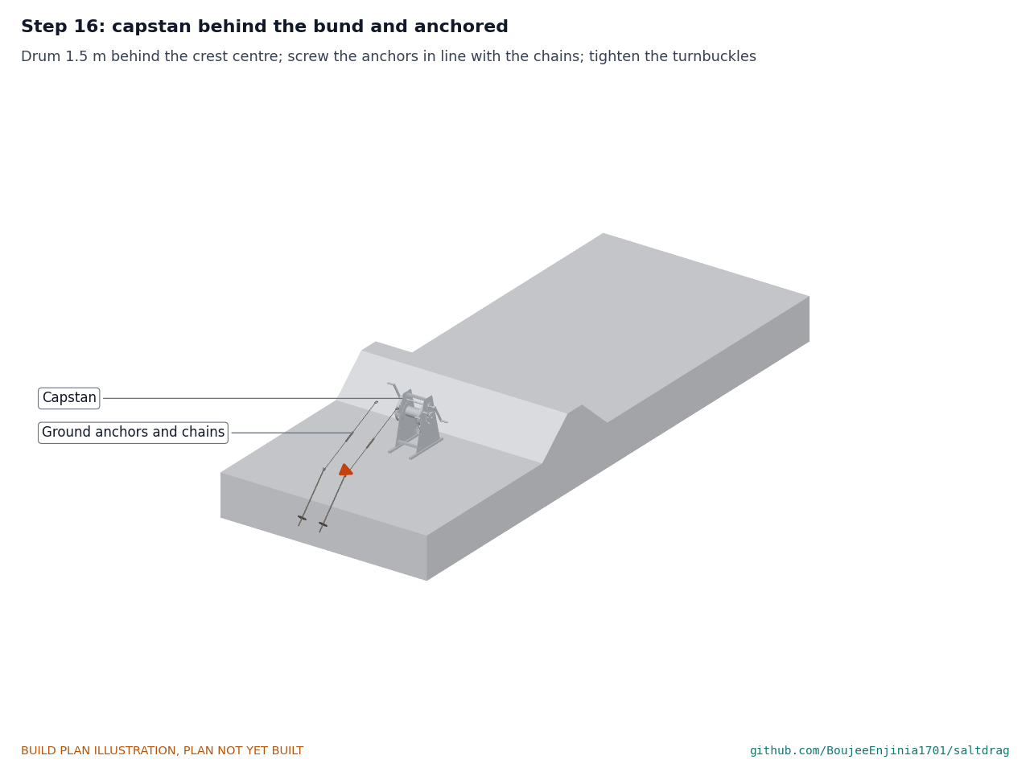
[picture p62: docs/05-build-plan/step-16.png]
Step 16


Stand the capstan on firm, level ground with its drum 1.5 m behind the bund crest centre and square to the strip to be raked. Screw the two anchors in 1.7 m behind the drum, in line with the chains, until only the eye shows. Shackle the chains to the ears and take up the slack with the turnbuckles.

### Step 17: roller on the crest and rope to the rake

Step 17

Set the saddle astride the crest in line with the drum. Walk the rope end round the pan on the bunds to the rake, lay it over the roller and shackle its eye to the pull bridle swivel. Rig the far capstan to the return bridle the same way.

### Step 18: ballast bags

Step 18

Fill two bags with about 24 kg of salt each and strap them on the beam behind the blade, 800 each side of the middle.

## 5. First checks

These are the checks a TRL 4 test report would record; this plan only lists them. Requirement numbers are those of SDG-REQ-001.

*Table 2. First checks.*

| Check | Requirement | How | Pass when |
| --- | --- | --- | --- |
| Gear mesh and free running | R2 | Turn each capstan by hand with no rope load | Smooth; backlash 0.2 to 0.5 mm; no rubbing on the guard |
| Pawl holds | R11 | Wind in, let go of the cranks under a 0.5 kN load from a spring scale | The pawl catches within one tooth; nothing moves |
| Brake holds and pays out | R11 | Cranks removed, pawl lifted, 3 kN load from CalRig | The brake holds with 150 N or less on the lever and pays out smoothly as it is eased |
| Proof load | R3, R10 | CalRig in line with the rope, anchored capstan, load to 4.5 kN (1.5 times rated) and hold 2 min | No permanent set in shafts, frames, ears or bolts; rope and splices undamaged |
| Anchors on site | R11 | Pull each anchor in line with its chain to 2.25 kN (1.5 times its share of the rated pull) | It moves less than 25 mm and holds for 2 min |
| Crank force | R2 | Spring scale on a handle while two people wind the rake with a full heap | 120 N or less at each handle |
| Blade height | R4 | Rake on a flat floor | 10 mm under the blade along its length |
| Rope stored | R12 | Wind on the full 45 m | Four even layers or fewer; at least 24 mm of flange left |
| Weights | R6 | Weigh each part | None over 25 kg |
| Set-up time | R8 | Time two crews setting up from a pan's edge | 20 min or less |

## 6. Safety stops

Stop at each point. Carry on only when everything listed is true.

- **S1. Before any part is welded or galvanised.** Steel is bare; welding is done in a ventilated space with screens; nobody welds galvanised steel.
- **S2. Before the first rope load.** The rope certificate shows at least 25 kN; the splice and thimble are whole; every shackle is moused; the pawl clicks into every tooth; the gear guard is on.
- **S3. Before any load above 0.5 kN.** The capstan is anchored with both chains tight; the frame's bolts are tightened; the rope damper bag hangs on the rope mid-span; nobody stands in line with the rope, behind the rake or on the bund within 2 m of the rope.
- **S4. Before paying out under load.** Both crank handles are off; one person holds the brake lever; the pawl is lifted only after the brake is on.
- **S5. Before the proof load.** CalRig is in line with the rope, its own anchor is checked, and the crew stands clear to the sides. Load in steps of 1 kN; stop and unload at any noise, slip or bending.
- **S6. Before the first pass on a pan.** Both anchors have passed their on-site pull; the bund roller sits square on the crest; the far capstan crew has the brake; the pan is clear of people and animals; shade and water are set up and work is planned for the cooler hours.
- **S7. At every move to the next strip.** The rope is slack and the pawl and brake are on before chains are unshackled; anchors are re-set and re-tensioned before the next load.

## 7. Tools, skills and workspace

**Tools.** Plasma, oxy-fuel or laser cutting for 6 to 20 mm plate (or a supplier who cuts to drawing); metal-cutting bandsaw or cut-off saw; pillar drill with drills to 25 mm and a 60 mm hole saw or boring; MIG or stick welder; lathe with 400 mm swing for the drum rim and keyways (or a machine shop); keyway broach or milling; plate rolls for the brake band and rim (or a supplier); angle grinder; taps and dies to M24; spanners and a torque wrench to 200 N·m; carbide or HSS drills and a dust extractor for FRP; wood bits for UHMW-PE; rivet tools for the brake lining; spring scale to 500 N; access to a CalRig proof-load rig to at least 5 kN; scales to 50 kg; tape and a long straightedge.

**Skills.** A fabricator who welds structural steel and reads drawings; a machinist for the drum, keyways and shafts; a rigger or someone trained in rope and shackle work for rigging and proof loading. No certified trade is needed beyond a competent welder, but proof loading and rigging must be supervised by someone who has done it before.

**Workspace.** A fabrication shop with a 3.5 m clear bench or trestles for the rake; a ventilated welding bay; galvanising done by a galvanising works; a firm yard at least 50 m long for the proof load, with an anchor point rated above 10 kN.

**Personal protective equipment.** Welding helmet, gloves and jacket; safety glasses and hearing protection for cutting and grinding; dust mask and gloves for FRP; safety boots and rigger's gloves for rope work and lifting; hats, light clothing, shade and water for work in the pans.

## 8. Where the numbers come from

- Model and constructability checks: `cad/src/model.py` (`python cad/src/model.py --check`); STEP and STL exports in `cad/step/` and `cad/stl/`.
- Pictures: `cad/src/build_plan_media.py`, using `.kit/build_views.py`; written to `docs/05-build-plan/` and `cad/drawings/SDG-DWG-101` to `SDG-DWG-113`.
- General arrangement: `cad/drawings/SDG-DWG-001.pdf`, Rev P2.
- Calculations: `docs/04-calcs/01-sizing.md` (SDG-CAL-001 v0.2) and `docs/04-calcs/sizing.py`; strength [C1] to [C14], lift-off [D3] and [D4], set-up [D10], masses [E1].
- Bill of materials: `bom/bom.csv`.
- Decisions: `docs/decisions/0002-design-for-construction.md` (SDG-DDR-002) and `docs/decisions/0001-trl2-review-decisions.md` (SDG-DDR-001).
- Requirements: `docs/03-requirements.md` (SDG-REQ-001 v0.3).

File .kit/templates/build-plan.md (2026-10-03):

---
doc_id: PRJ-BLD-001
title: Project prototype build plan
project: Project name
doc_type: Build plan
version: "0.1"
status: Draft
date: YYYY-MM-DD
author: Amish Chadha
license: CERN-OHL-S-2.0
revisions:
  - version: "0.1"
    date: YYYY-MM-DD
    author: Amish Chadha
    change: First build plan; design made constructable
---

# Project prototype build plan

**Plan, not yet built.** How to build the first proof-of-concept prototype, component by component. Building and testing to it is TRL 4 work. Decisions still to be made are kept in the design decisions register (`docs/06-design-decisions.md`), not here.

## 1. What you are building

Every component, pulled apart and numbered in build order

One short paragraph: what the prototype is, how many components, which are made and which are bought, and the main ways they are made.

## 2. What changed to make it buildable

| Component | The concept had | The buildable design has | Why |
| --- | --- | --- | --- |

## 3. Making the components

### 3.1 Component name

Making sketch

**What it is and what it is made from.**

**How to make it.**

1. Mark out ...
2. Cut ...

**How it fits the parts next to it.**

Close-up of the joint

**Check before moving on.**

## 4. Putting it together

### Step 1: ...

Step 1

## 5. First checks

| Check | Requirement | How | Pass when |
| --- | --- | --- | --- |

## 6. Safety stops

## 7. Tools, skills and workspace

## 8. Where the numbers come from

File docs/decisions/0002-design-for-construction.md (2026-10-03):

---
doc_id: SDG-DDR-002
title: SaltDrag design for construction
project: SaltDrag
doc_type: Design decision record
version: "0.1"
status: Draft
date: '2026-10-03'
author: Amish Chadha
license: CERN-OHL-S-2.0
revisions:
- version: "0.1"
  date: '2026-10-03'
  author: Amish Chadha
  change: Changes that make the concept physically buildable, with the reason for each; made under Amish's 2026-10-03 pre-approval
---

# 0002: Design for construction

- **Date:** 2026-10-03
- **Status:** accepted. Decided by Amish under his pre-approval of 2026-10-03: "start with the first 14 repos from the list of 29 projects. I pre-approve the batch runs along with any recommendations you come up with. I also accept any cost overruns or variations from the assumed scope cost." The standing instruction for this step (Amish, 2026-09-30) is to "fix the design assumptions to match and be physically feasible".

## Context

The concept described portable geared drums "staked on the bunds", a rake "in bolted sections", ropes, bridles and a windrow board, without saying how any part is made or how it joins its neighbours. The constructability review went component by component through how each is made and fixed, and checked the parametric model for overlaps, floating parts and clearances with build123d (`python cad/src/model.py --check`: 63 of 63 checks pass).

## Changes

*Table 1. Changes from the concept to the constructable design.*

| # | Component | The concept had | The constructable design has | Why |
| --- | --- | --- | --- | --- |
| 1 | Capstan frame | A portable geared drum, no frame described | Two side frames (6 mm cheek welded on a 40 mm box runner) bolted together by three cross tubes with end plates | Each side frame is under 21 kg and the frame comes apart for carrying (R6); bolted tubes let the drum go in between the cheeks |
| 2 | Capstan position | Staked on the bund | On dry ground behind the bund, drum 1.5 m behind the crest centre, with a roller saddle on the crest | The crest is too narrow to stand on while cranking; the roller keeps the rope off the bund |
| 3 | Drum | A drum | Welded drum: 168 mm pipe barrel, 330 mm flanges, a brake rim on the left flange, a 40 mm shaft welded through; rope wound over the top | The flanges hold 58 m of rope in four layers; rope leaving the top is level with the roller, so it does not lift the capstan |
| 4 | Shaft supports | Not shown | Four-bolt flange bearings bolted to the cheeks, shafts through clearance holes | Bought bearings in stainless and thermoplastic for brine; holes leave 5 to 10 mm of clearance |
| 5 | Gearing | "Geared" | Bought module 4 gear (84 teeth, webbed) and pinion (14 teeth), keyed on; the pinion overhangs outside the right bearing | One stage gives 6 to 1; a webbed gear is 10 kg instead of 22 kg solid |
| 6 | Ratchet and pawl | A ratchet pawl | 20-tooth ratchet wheel on the drum shaft; the pawl on a 40 mm boss welded to the left cheek, with an M24 pivot bolt | A plain pin cantilevered from the cheek would bend at 6 kN (SDG-CAL-001, Section C) |
| 7 | Brake | A brake | Differential band brake: a lined steel band round the brake rim, both ends to a lever pivoted through the left cheek | Holds the rated pull with a 92 N hand force; no extra drum needed |
| 8 | Cranks | Crank handles | Two removable cranks on hubs with cross pins, set 180 degrees apart, on a 25 mm crank shaft in its own bearings | Removable so they are off whenever rope is paid out under load (SDG-DDR-001, D9) |
| 9 | Gear guard | None | A yellow 2 mm steel cup over the gear mesh on three spacers | Covers the nip between gear and pinion |
| 10 | Anchoring | "Screw or plate anchors" | An ear on each cheek at rope height, a shackle, chain and turnbuckle to a screw-in helical anchor 1.7 m behind | Chain at rope height keeps the capstan from tipping (1.55 times the tipping moment) |
| 11 | Rake beam | Bolted sections | One 3.0 m FRP box beam, 100 x 100 x 6 mm | At 12.8 kg one piece is carried by two people; no splice to wear in brine |
| 12 | Blade fixing | Not shown | Ten countersunk M10 stainless bolts through blade and beam, with stainless crush sleeves inside the tube | The sleeves stop the bolts crushing the FRP |
| 13 | Skids | Height-setting skids | Three UHMW-PE skids on L-shaped stainless hangers bolted to the beam's back face through slots | The slots set the blade 5 to 25 mm above the floor |
| 14 | Bridle fixing | "Bridle and swivels" | Stainless end caps on the beam ends with welded eye plates; bridles shackled to the eyes, front and rear | Pulls the beam at its ends through a part made for the load; the beam's bending stays at 28 MPa at 6 kN |
| 15 | Ballast | None | Two woven bags of about 24 kg of salt strapped on the beam behind the blade | Without them the rising rope lifts the blade 5.9 m from the bund toe; with them, 3.3 m (SDG-CAL-001, Section D) |
| 16 | Windrow board | A board at the bund edge collects the salt | Removed | The rake lifts before it reaches the bund edge, so a board there would collect nothing; the windrow forms about 3.3 m from the toe |
| 17 | Rope dampers | None | A weighted bag on each loaded rope | Snap-back protection (SDG-DDR-001, D10) |

## What did not change

What the product does, its pitch and its safety case are unchanged: two hand capstans on the bund side wind a rake across the pan and nobody enters the brine. The windrow position (change 16) and the ballast (change 15) follow from physics the concept had not checked, and both were made under the pre-approval.

## Consequences

- New BOM lines: 6b (25 mm bearings), 11b (chains and turnbuckles), 12 (bund roller saddle), 20 (rope dampers), 22 (ballast bags), 23 (fabrication labour and galvanising).
- General arrangement SDG-DWG-001 goes to Rev P2; making sketches SDG-DWG-101 to 113 are new.
- Concept media, STEP and STL files are regenerated from the constructable model.
- `design_state: constructable` in `project.yaml`.

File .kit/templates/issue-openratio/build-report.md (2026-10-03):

---
name: Build report
about: Tell us what happened when you built, printed or tested part of this design
title: "Build report: "
labels: build-report
---

This is a research and educational prototype, not a medical device. It is a TRL 3 concept and is not released for fabrication. If you build any part of it, you do so at your own risk. Reports help everyone.

**What you built** (part, sub-assembly or test)

**Materials, tools and settings**

**What worked**

**What did not work, with photos or measurements if you have them**

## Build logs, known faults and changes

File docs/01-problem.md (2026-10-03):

---
doc_id: SDG-PRB-001
title: SaltDrag problem statement
project: SaltDrag
doc_type: Problem statement
version: "0.2"
status: Draft
date: '2026-10-03'
author: Amish Chadha
license: CERN-OHL-S-2.0
revisions:
- version: "0.1"
  date: '2026-09-30'
  author: Amish Chadha
  change: Initial scaffold
- version: "0.2"
  date: '2026-10-03'
  author: Amish Chadha
  change: TRL 2 update; site assumptions made explicit, co-design checklist, safety section, open questions answered where the TRL 3 work settles them (SDG-DDR-001)
---

# SaltDrag problem statement

Brine pumping in the Little Rann has been modernised; gathering the salt has not.

## The problem

Agariyas dig wells for underground brine, build pans with two-foot embankments, harden the floors by hand and pump brine in to evaporate over the winter ([Press Institute of India](https://pressinstitute.in/grassroots/traditional-salt-workers-contribute-to-wild-ass-conservation-and-regain-access-to-little-rann-of-kutch/)). The salt is then scraped with a large hand tool called a dantala ([Mongabay India, 2021](https://india.mongabay.com/2021/10/when-salt-is-an-essential-commodity-and-salt-makers-are-not/)). A family can produce 500 to 600 tonnes a year from one pan ([Business Standard, 2009](https://www.business-standard.com/article/companies/growing-pan-of-worries-livelihood-of-over-45k-agariyas-in-jeopardy-109080500047_1.html)), which is a great deal of scraping by hand inside the pan.

The preliminary IP screen found expired and active patents for salt harvesters and salt-pan rakes, but these assume machines. Agariyas' registration cards require them to avoid machine use ([ICSF](https://icsf.net/newss/gujarat-in-kutch-booming-salt-business-puts-traditional-salt-agariyas-up-against-ginger-prawn-fishers/)), and their earnings are a small share of the retail price. The gap is a hand-powered tool, owned by the families, that gathers salt while the worker stays on the bund.

## Users and context

| User | Need | Context |
| --- | --- | --- |
| Agariya salt-making families | Gather salt with less time inside the pan and less direct handling | Family pans in the Little Rann during the March to April harvest |
| Women salt workers | A tool that does not need great upper-body strength and can be worked from the bund | Shared family labour in the pans |
| Producer groups and NGOs | A shareable, repairable kit they can fund and train people on | Clusters of pans; existing solar pump programmes |
| Local fabricators | Drawings they can build from steel pipe, rope and bearings | Workshops in towns around the Rann |

## Operating environment

- Flat pans with bunds of about 0.6 m (2 ft) height; pan widths of tens of metres. The design case is a pan 30 m across between bund crests, with bunds about 0.4 m wide at the crest and 1.8 m at the base, and dry, firm ground behind the bunds on the two sides where the capstans stand (assumptions, to be surveyed at the first trial pan).
- Crystallised salt bed under shallow brine; hand-hardened pan floor that must not be damaged.
- Extreme heat in the March to April harvest and cold winters; strong sun, wind and dust.
- Highly corrosive brine and salt; no mains power; long distances to repair shops.
- Protected wildlife sanctuary with rules on structures and machines.

## Constraints

- Prototype budget ceiling of $4,000 USD in parts for two capstans, rake, ropes and anchors.
- Hand power only; no engines or motors, to fit Agariya registration rules on machine use.
- Must not damage the hand-hardened pan floor.
- Corrosion-resistant materials or coatings throughout; repairable with local tools.
- Portable between pans by two to four people; no permanent structures in the sanctuary.
- Hardware under CERN-OHL-S-2.0; published as an open engineering reference, not certified equipment.

## Safety

> **Safety:** Gathering salt with ropes and hand capstans brings three hazards that hand scraping does not: a loaded rope that can break or slip and whip back, cranks and gears that can strike or trap a hand, and ground anchors that can pull out. The design answers each one (SDG-PRC-001, Safety), and the build plan has safety stops before the first load. Heat remains the largest everyday hazard in the March to April harvest, whatever tool is used.

## Out of scope

- Brine pumping (solar pumps already serve this).
- Salt washing, drying, grading or transport.
- Motorised or tracked harvesters.
- Large industrial salt works.

## Prior work

| Prior work | What it does | Gap for these users | Source |
| --- | --- | --- | --- |
| Dantala hand scraper | Large hand tool used by Agariyas to scrape salt in the pans | Worked from inside the pan with direct handling of salt | [link](https://india.mongabay.com/2021/10/when-salt-is-an-essential-commodity-and-salt-makers-are-not/) |
| Traditional Agariya pan method | Brine wells, two-foot bunds, hand-hardened pan floors, winter evaporation | No tool for gathering salt from the bund | [link](https://pressinstitute.in/grassroots/traditional-salt-workers-contribute-to-wild-ass-conservation-and-regain-access-to-little-rann-of-kutch/) |
| Solar brine pumps in the Little Rann | Solar pumps replacing diesel for brine lifting, now used by most Agariya families | Solves pumping only; harvest remains manual | [link](https://www.downtoearth.org.in/news/renewable-energy/great-change-in-little-rann-how-salt-workers-on-the-brink-in-gujarat-brought-about-a-solar-revolution-80652) |

## Co-design

A women-led producer organisation or NGO already working with Agariya families on solar pumps or livelihoods, so that harvest trials sit inside an existing trust relationship and the tool is shaped by the people who will wind it. The first candidate to approach is the Self Employed Women's Association (SEWA), which works with salt-farming families in the Little Rann; nothing has been agreed (SDG-DDR-001).

Co-design checklist, to complete with the partner before the first trial:

- [ ] Agree the trial pans and the families who host them.
- [ ] Measure the drag of a rake on a typical crystal bed (the main unknown in SDG-CAL-001).
- [ ] Time the dantala method on the same pans, to set the gathering-rate baseline for R5.
- [ ] Check with the forest department, through the partner, that a hand capstan is not a machine under the registration conditions.
- [ ] Survey bund sizes, pan widths and the ground behind the bunds.
- [ ] Agree work hours, shade and water for trials in the harvest season.

## Open questions

The TRL 3 work answers some of the scaffold's questions on paper; the rest can only be settled on a pan.

| Question | Where it stands |
| --- | --- |
| What is the drag force per metre of rake on a typical Agariya crystal bed? | Estimated at about 0.9 kN per metre with a full heap (SDG-CAL-001); to be measured with the partner before the first build is loaded. |
| Would the forest department regard a hand capstan as a machine under the registration conditions? | The design has no engine or motor. Written clarification is sought through the partner before any trial (SDG-DDR-001). |
| How wide are typical pans, and can one rake span them? | One rake 3.0 m wide works strip by strip across pans up to about 45 m between the capstans; the design case is 30 m. |
| Can the rake gather large Vadagra crystals without crushing them or damaging the floor? | The blade rides 10 mm above the floor on plastic skids and pushes rather than scrapes; crystal damage is to be checked in trials. |
| Which producer organisation would host the first trial pans? | SEWA is the first candidate to approach; nothing is agreed. |

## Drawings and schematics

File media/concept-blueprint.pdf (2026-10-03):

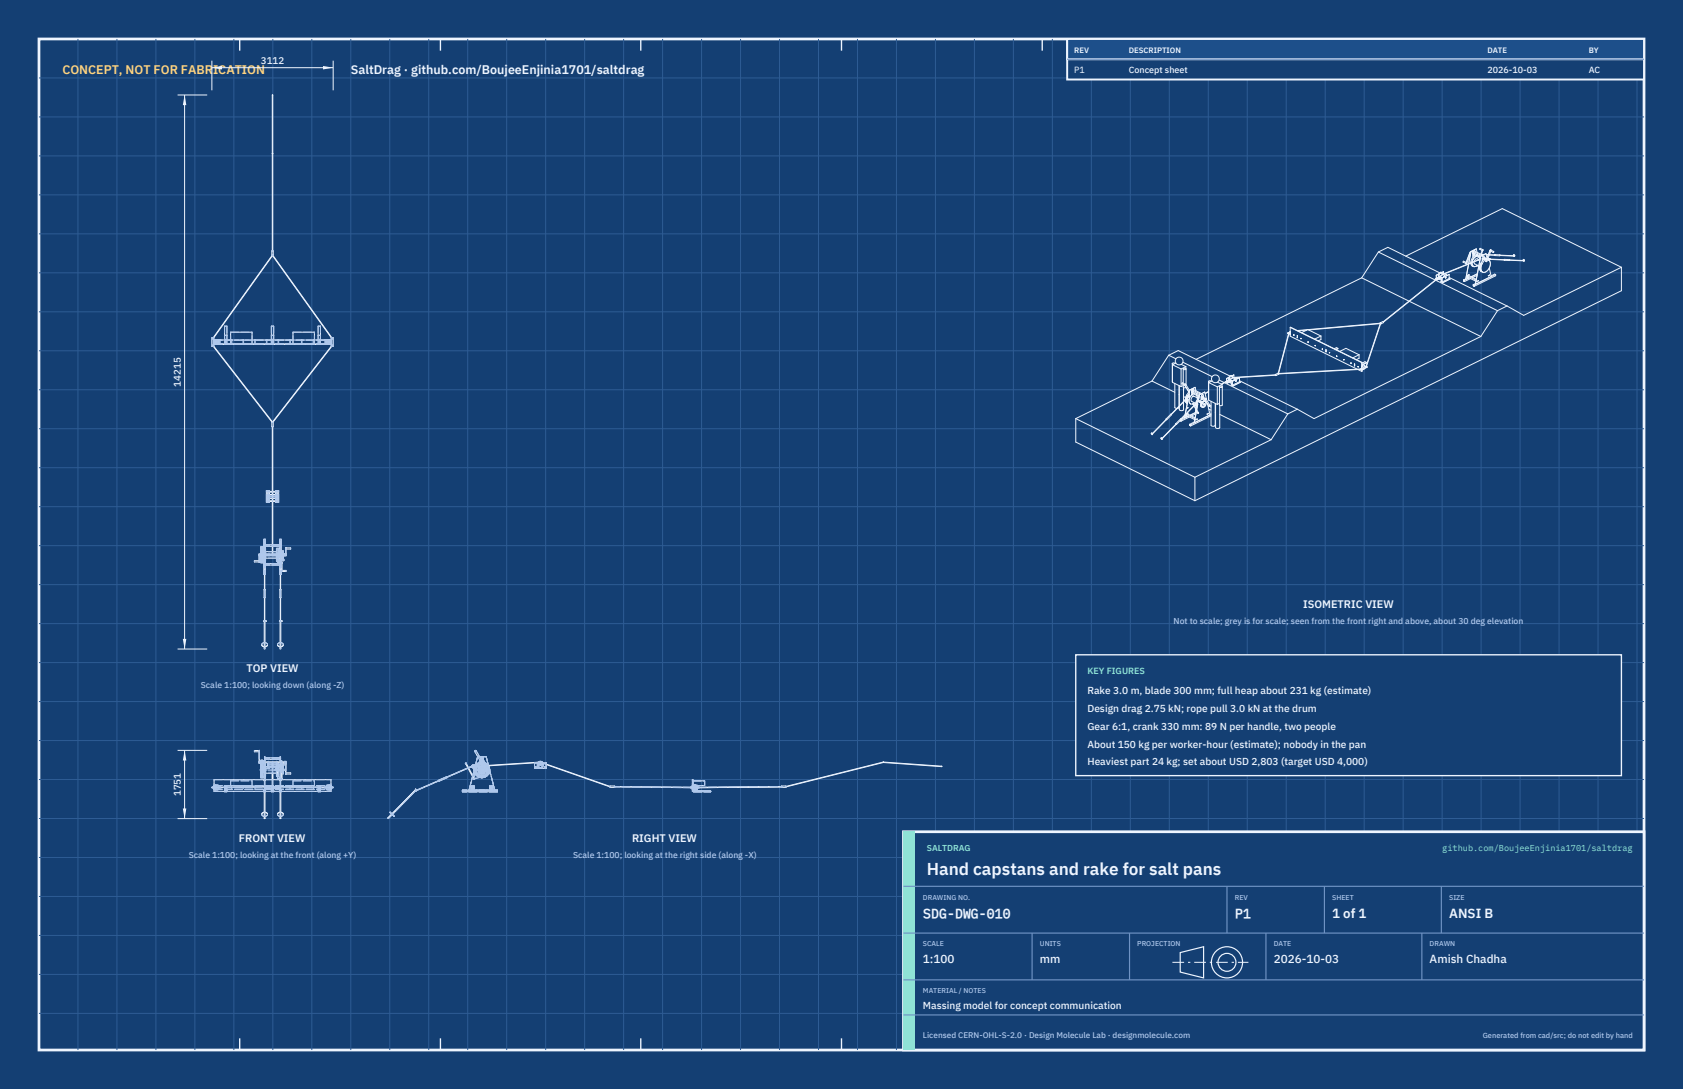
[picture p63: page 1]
CONCEPT, NOT FOR FABRICATION; SaltDrag · github.com/BoujeeEnjinia1701/saltdrag; FRONT VIEW; TOP VIEW; RIGHT VIEW; ISOMETRIC VIEW; REV; DESCRIPTION; DATE; Concept sheet; SALTDRAG; github.com/BoujeeEnjinia1701/saltdrag; DRAWING NO. SDG-DWG-010; REV P1; SHEET 1 of 1; SIZE ANSI B; SCALE 1:100; UNITS mm; PROJECTION; DRAWN Amish Chadha; Licensed CERN-OHL-S-2.0 · Design Molecule Lab · designmolecule.com; Generated from cad/src; do not edit by hand

Not to scale; grey is for scale; seen from the front right and above, about 30 deg elevation

KEY FIGURES
Rake 3.0 m, blade 300 mm; full heap about 231 kg (estimate)
Design drag 2.75 kN; rope pull 3.0 kN at the drum
Gear 6:1, crank 330 mm: 89 N per handle, two people
About 150 kg per worker-hour (estimate); nobody in the pan
Heaviest part 24 kg; set about USD 2,803 (target USD 4,000)

Scale 1:100; looking down (along -Z)

Scale 1:100; looking at the front (along +Y)

Scale 1:100; looking at the right side (along -X)

Hand capstans and rake for salt pans

MATERIAL / NOTES
Massing model for concept communication

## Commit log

2026-10-03 SaltDrag at TRL 3: constructable design (kit 1.7.0)
    Problem, concept and requirements; sizing calculations; CAD model, STEP and STL; general arrangement drawing; bill of materials; build plan with making sketches, joint close-ups and step pictures; design decisions register (all decided under Amish's 2026-10-03 pre-approval); TRL 2 and TRL 3 review; photoreal renders and storefront card. Private until Amish opens it.
    [bom.csv, results.csv, saltdrag-assembly.step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]
2026-10-03 Carry Amish's 2026-10-03 requirement decisions into the design
    Amish chose option A on each requirement decision ("1A 2A 3A 4A 5A 6A 7A 8A 9A 10A 11A"). CampBreak: primed foot valve, pre-coupled suction hose and a drilled 30 s gather (R9 now 3.2 min at 100 m, me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
2026-10-28 Kit 1.9.1 upgrade: pipeline documents and detailed CAD for every option
    Kit 1.9.1 installed (.kit, CLAUDE.md, .claude/commands). Kit 1.8 pipeline: STEM check with fixes under the 2026-10-23 standing instruction, concept options with the current design as option A, URS, PRS, generated RTM, REG, FEA, RSK with design FMEA, MKT, PLN and DDR; kit 1.9 D3 model of every option passing cad/fidelity.json; independent review recorded in the STEM check. Amish's 2026-10-25 decisions recorded where he approved a recommendation; all others proposed, awaiting Amish. Product renders and the options picture follow in a later commit where not yet included.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
2026-10-29 Add Cycles product renders and the concept options picture
    Blender Cycles renders of the kit 1.9.1 model, rendered on Amish's Mac and captioned; media/options.png from the D3 option models (this also clears the failing docs check, which needs the picture); cards and PDFs rebuilt. The options picture labels option A as the current design unless project.yaml records Amish's choice.
2026-10-29 Add the concept options picture rendered from the D3 option models
    media/options.png from Blender Cycles panels of every option, rendered on Amish's Mac; the label reads CURRENT DESIGN unless project.yaml records Amish's choice. Clears the docs check, which needs th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

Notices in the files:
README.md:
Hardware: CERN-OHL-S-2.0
